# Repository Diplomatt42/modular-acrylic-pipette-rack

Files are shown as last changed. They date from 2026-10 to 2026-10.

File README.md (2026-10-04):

# Modular Acrylic Pipette Rack

Companies charge outrageous prices for equipment that scientists need to help people. This humble box project is small, but I hope it illustrates how AI can enable non-engineers like myself to quickly design products and make use of innovative companies like OSHCut and SendCutSend to reduce barriers for science.

It would be possible to create a 3D printable solution for ~$30 of filament. However, that requires a 3D printer and the hassle of managing multiple print jobs with a risk of failed prints. For not much added cost, this design eliminates that hassle and enables the use of on demand manufacturing services like OSH Cut or SendCutSend. If you have access to a laser cutter (for example through a shared University service), cost for acrylic material would be comparable to 3D printing.

This project offers two designs for the storage of serological pipettes. The solid design recreates existing storage solutions, and the column design was created to reduce material cost.

Two modular, laser-cut acrylic rack designs: **solid sides** and **corner
columns**. Stack identical compartments vertically while sharing one shelf at
each interface, instead of doubling the floor and ceiling. Designed for easy dry-fit assembly
and optimized for flat-pack shipping.

**[Download the solid CAD package](https://github.com/Diplomatt42/modular-acrylic-pipette-rack/releases/download/v1.1/solid_version_3mm_editable_CAD_package_v1.1.zip)**
| **[Download the column CAD package](https://github.com/Diplomatt42/modular-acrylic-pipette-rack/releases/download/v1.1/column_version_3mm_editable_CAD_package_v1.1.zip)**
| **[Release notes](https://github.com/Diplomatt42/modular-acrylic-pipette-rack/releases/tag/v1.1)**

Each download is a complete folder with CAD, editable source, configuration,
assembly notes and an AI handoff guide. You can use the delivered DXF/STEP files
without installing the generator.

> [!WARNING]
> Acrylic can craze or crack from alcohol-based cleaners, even in a dry-fit rack that doesn't use solvent welding.
> For regular alcohol cleaning, I strongly recommend a compatible polycarbonate
> or PETG grade instead. Verify the exact cleaner and fabrication process.
> See [solid guide](solid-version/MATERIALS_AND_CARE.md) or [column guide](column-version/MATERIALS_AND_CARE.md).

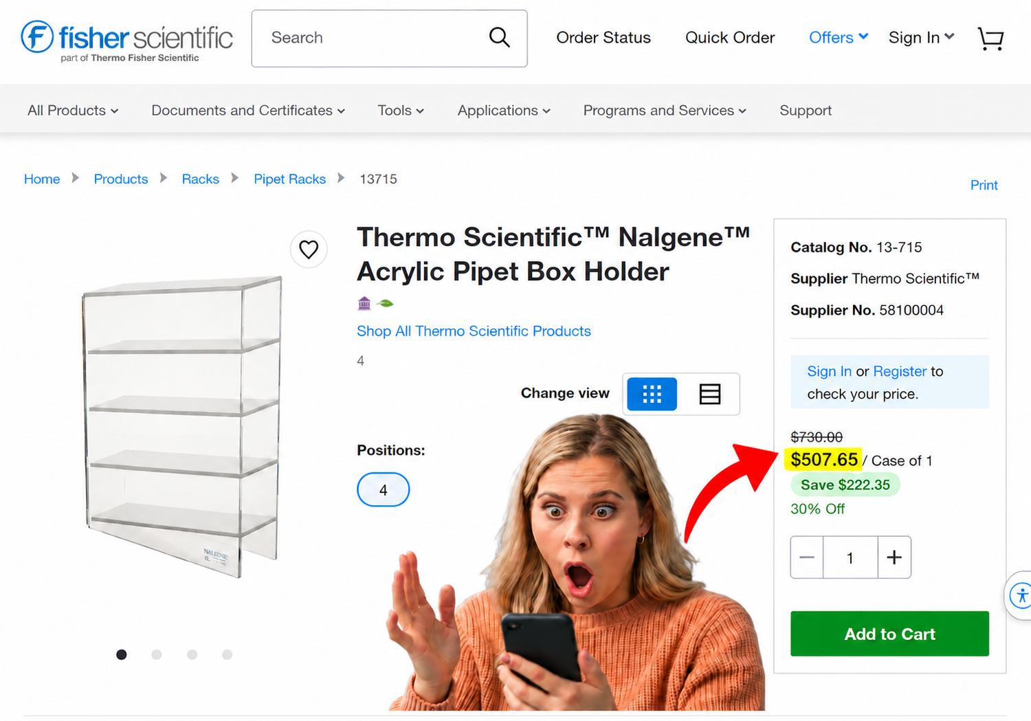
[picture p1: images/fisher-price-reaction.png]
Shocked reaction to the $507.65 Fisher Scientific product price


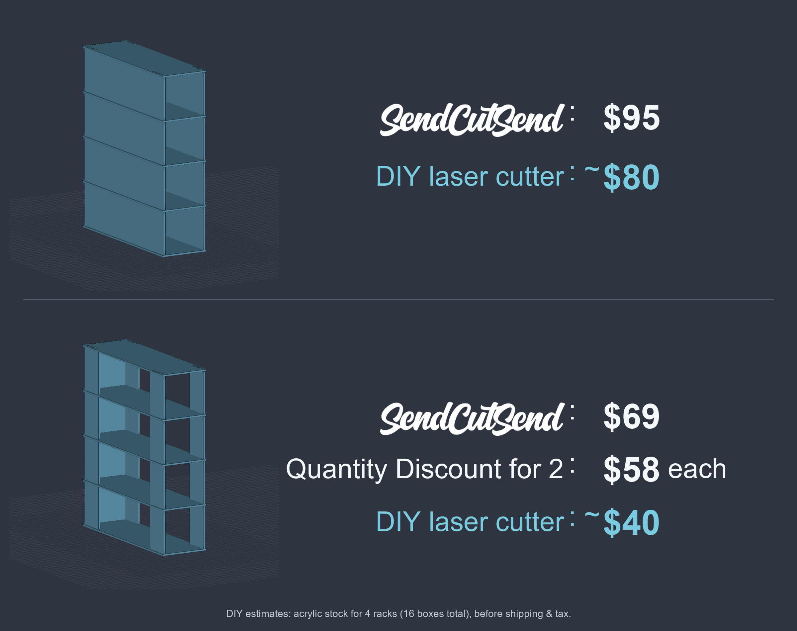
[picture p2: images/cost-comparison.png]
Solid and column rack comparison


*The SendCutSend prices are supplied quotes. DIY prices in the image are estimated
acrylic stock totals for a batch of four complete racks (16 compartments), before
shipping and tax. They are not per-rack DIY prices. Get current quotes for the same
quantity and specifications when comparing fabrication options.*

## Choose a version

| | Solid sides | Corner columns |
|---|---|---|
| Side support per compartment | Two full panels | Four identical columns |
| Column width | Not applicable | 2.000 in / 50.8 mm |
| Unique production parts | Side panel, shelf, back | Column, shelf, back |
| Four-compartment quantities | 8 sides, 5 shelves, 4 backs | 16 columns, 5 shelves, 4 backs |
| Package | [solid-version/](solid-version/) | [column-version/](column-version/) |

## Dimensions and material

- Nominal material: 3 mm clear acrylic.
- Existing model thickness: 0.118 in / 2.9972 mm; customize to measured stock.
- Body width x depth: 3.500 x 11.500 in / 88.9 x 292.1 mm.
- One complete box height: 3.500 in / 88.9 mm, including both shelves.
- Clear compartment height: 3.264 in / 82.9056 mm.
- Shelf footprint: 3.750 x 11.625 in / 95.25 x 295.275 mm.
- Four-compartment overall height: 13.646 in / 346.6084 mm.
- For N compartments: N+1 shelves, N backs, and 2N sides or 4N columns.

The default laser profile assumes a 36 x 24-inch bed. Change it to match both your
actual usable laser bed and stock dimensions. DXFs use **inches**; STEP uses **mm**.

## Assemble

1. Put the first shelf flat on a level counter.
2. Insert two sides (or four columns) and one back; temporarily support the walls.
3. Cap the compartment with a second identical shelf.
4. Add the next walls onto that shared shelf and repeat.

Upper and lower wall tabs use offset slot sets, so they do not collide at shared
shelves. Follow the assembly model for front/back and top/bottom orientation.
Full instructions: [solid assembly](solid-version/ASSEMBLY.md) /
[column assembly](column-version/ASSEMBLY.md).

## Slot locations, edges and corner radii

Hole locations and deliberately non-flush shelf edges enable the tab-and-slot
joints. The shelves extend beyond the wall faces to leave material around their
slots. Offset upper/lower slot sets let the walls above and below a shared shelf
use different openings without their tabs colliding. These offsets are intentional;
do not center the holes or trim the shelves flush without redesigning the joints.

Slots are rectangular with small **0.381 mm (0.015 in) corner radii**, preserving
the v1.0 dimensions and fit. They do not have full semicircular ends. Small radii
avoid sharp internal corners; they do not guarantee freedom from stress fractures.
Side slots are 15.24 x 3.8862 mm; back slots are 12.192 x 3.8862 mm. The default
0.889 mm thickness clearance remains a locating slip fit; cut the fit coupon to
choose a closer positive clearance for your stock and machine.

## Customize, or hand the package to an AI agent

Start with `AI_HANDOFF.md` in the chosen version. Edit `design_parameters.json`
for dimensions and joints, and `laser_profile.json` for bed size and cut spacing.
The JSON inputs use mm, including the box height, actual stock thickness and fit
clearances. The generator recomputes the mating parts and shared-shelf stack.

Example request:

> Change the single-box overall height to 101.6 mm, keep the shared shelf system,
> and regenerate the one-box and four-compartment STEP models and production
> DXFs. Validate the CAD and report the new clear opening height.

The source uses Python, CadQuery and ezdxf. Setup and regeneration instructions
are in each package's README. Use a new output folder to preserve earlier revisions.

| Reference | Solid | Column |
|---|---|---|
| Editable inputs and instructions | [README](solid-version/README.md) | [README](column-version/README.md) |
| AI handoff | [AI_HANDOFF.md](solid-version/AI_HANDOFF.md) | [AI_HANDOFF.md](column-version/AI_HANDOFF.md) |
| Laser customization | [CUSTOMIZATION.md](solid-version/CUSTOMIZATION.md) | [CUSTOMIZATION.md](column-version/CUSTOMIZATION.md) |
| Three production DXFs | [cutting/](solid-version/generated/cutting/) | [cutting/](column-version/generated/cutting/) |
| Individual and assembled STEP | [models/](solid-version/generated/models/) | [models/](column-version/generated/models/) |

## Prototype status and validation

**CAD-validated prototype; physical testing is still needed.** No load rating or
unlimited safe stack height is claimed. The joints are gravity-assembled locating
slip fits; they do not positively retain the stack when lifted by its top.

The rack was designed to be modular, dry-fit together for easy assembly, and
optimized for flat-pack shipping. All production parts are flat sheet pieces that
can ship disassembled. Walls need temporary support until the next shelf is fitted.

If additional stability is needed, acrylic can be permanently solvent welded with
a compatible acrylic cement. Where permitted under approved lab controls,
methylene chloride and a needle applicator can be used at close-contact seams;
other acrylic cement formulations are available. Bonding prevents disassembly at
those joints. See the [solid](solid-version/MATERIALS_AND_CARE.md) or
[column](column-version/MATERIALS_AND_CARE.md) material guide for joint-gap guidance,
chemical precautions, and the [author's example cement link](https://a.co/d/034aoZOj).

Checks passed for closed DXF contours, solid geometry, assembly collisions, STEP
reimport, dimensions, part quantities and bed-layout spacing. The rewritten source
also reproduces the previously shared parts. The v1.1 documentation release
retains the v1.0 CAD geometry and confirms the small rounded slot corners in both
versions. Tested customizations include height
changes and changes to stock thickness, clearance, bed size and compartment count.

Cut a fit coupon with your stock and settings, then prototype one compartment.
DXFs describe finished geometry; apply kerf compensation once in your laser CAM.
Changing the modeled thickness alone does not calibrate your laser.

See each version's `BASELINE_CHECK.json` and `generated/validation_report.json`
for the actual checks. Local nested drawings are separate from the individual
supplier DXFs and do not guarantee the fewest possible sheets.

## License and credit

Original project material is licensed under **[CC BY 4.0](https://creativecommons.org/licenses/by/4.0/)**.
You can use, modify and redistribute it, including commercially, with attribution,
a license link and an indication of changes. Copyright is retained to the extent
it applies. See [LICENSE](LICENSE) and [ATTRIBUTION.md](ATTRIBUTION.md).

Third-party libraries and the SendCutSend logo/trademarks retain their own rights.
This project is not affiliated with or endorsed by SendCutSend.

## Feedback and contributions

Open an issue with your variant, stock thickness, machine/setup, changed parameters
and the problem encountered. If you submit improved geometry or instructions,
include matching source/input changes and regenerated validation results.

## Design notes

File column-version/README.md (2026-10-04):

# Editable 3 mm acrylic modular box: column version

This package includes finished CAD files and the editable inputs needed to change
the design. It uses four identical 2-inch columns, one at each corner, one back panel per compartment,
and one shelf at each horizontal interface. Adjacent compartments share a shelf.

The current CAD is a gravity-assembled locating **slip fit**, not a press-fit or
positively locked assembly. Physical fit and load capacity have not been tested.

> [!WARNING]
> Acrylic can craze or crack from alcohol-based cleaners, even in a dry-fit rack that doesn't use solvent welding.
> For regular alcohol cleaning, I strongly recommend a compatible polycarbonate
> or PETG grade instead. Verify the exact cleaner and fabrication process.
> See [materials and cleaning guidance](MATERIALS_AND_CARE.md).

## Start here

- `generated/cutting/`: three unique, individual production DXFs.
- `generated/models/`: individual part STEP models, one complete compartment,
  and a four-compartment stack.
- `design_parameters.json`: dimensions and joint clearances, all in mm.
- `laser_profile.json`: laser bed, edge margin, spacing, and feature limits.
- `source/generate.py`: portable parametric source; no local machine paths.
- `generated/laser_layouts/`: nested DXFs for your own laser, plus placement data
  in the validation report. These contain multiple parts; do not upload them as
  individual SendCutSend parts.
- `generated/calibration/`: fit ladder and probe, with a separate slot map.
- `ASSEMBLY.md`, `CUSTOMIZATION.md`, `AI_HANDOFF.md`: assembly and editing guidance.
- `MATERIALS_AND_CARE.md`: alcohol warning, material choices and optional bonding.
- `generated/cut_list.csv`: quantities for the configured compartment count.
- `generated/validation_report.json`: actual checks and remaining limitations.
- `MANIFEST.sha256`: checksums of included files.

Designed for modular, easy dry-fit assembly and flat-pack shipping.
See ASSEMBLY.md for intentional joint offsets and non-flush shelf edges,
and MATERIALS_AND_CARE.md for cleaning, alternate materials and optional cement.

**v1.1 updates the documentation; delivered CAD geometry is unchanged from v1.0.**
The rectangular slots retain 0.381 mm corner radii and existing clearances.

## Default dimensions

| Dimension | Value |
|---|---|
| Body width x depth | 3.500 x 11.500 in (88.9 x 292.1 mm) |
| Single-box overall height, including both shelves | 3.500 in (88.9 mm) |
| Clear compartment height | 3.264 in (82.9056 mm) |
| Clear compartment width | 3.264 in (82.9056 mm) |
| Shelf footprint | 3.750 x 11.625 in (95.25 x 295.275 mm) |
| Four-compartment overall height | 13.646 in (346.6084 mm) |
| Column width / side joint zone width | 2.000 in (50.8 mm) |
| Nominal stock | 3 mm acrylic |
| Thickness used by existing CAD | 0.118 in (2.9972 mm) |
| Slot thickness width | 0.153 in (3.8862 mm) |

The 0.0028 mm difference between nominal 3 mm and the existing model is retained
to reproduce the already shared CAD. Set `stock_model_thickness` to your measured
sheet thickness when customizing; dependent dimensions are recalculated.

## Regenerate

Use Python 3.11 or 3.12 in a fresh virtual environment. The pinned dependencies
match the generator's tested environment. CAD dependencies are downloaded by pip;
they are not bundled in this ZIP.

Windows:

```powershell
python -m venv .venv
.venv\Scripts\python -m pip install -r requirements.txt
.venv\Scripts\python source/generate.py --output generated_custom
```

macOS / Linux:

```sh
python3 -m venv .venv
.venv/bin/python -m pip install -r requirements.txt
.venv/bin/python source/generate.py --output generated_custom
```

Edit the two JSON inputs first. The output directory must be new or empty; this
preserves previous revisions and prevents obsolete nested sheets from lingering.
Alternative inputs can be supplied with `--config` and `--laser-profile`.

## File units and compensation

Production and calibration DXFs are R2010, 1:1 **inch** units, using only LINE and
ARC cutting entities on layer 0. STEP models use **mm**. If an importer ignores DXF
units, select inches: the shelf is 3.750 x 11.625 inches, not millimetres.

These DXFs describe the desired finished geometry, not kerf-offset toolpaths.
`measured_kerf_mm` records your measurement; it does not offset the files. Let your
laser CAM compensate once, with the correct inside/outside direction. Cutting
on the line without compensation changes outside dimensions and slot widths.

## Quantity rule

For N compartments: N+1 shelves, N backs, and 4N columns. Four compartments
therefore use five shelves. Increasing the count does not duplicate an interface.

## Validation and limits

The generator audits DXF contours, imports the actual DXFs into CAD, validates
solid geometry, checks nominal body collisions, reimports assembly STEP files,
checks envelopes and bottom position, and verifies nesting bounds and spacing.
Feature-limit checks use editable targets in `laser_profile.json`; they are not
a blanket approval for any supplier, machine, thickness, or load.

Default nesting is conservative bounding-box packing. It does not prove the
fewest possible sheets. Fit-ladder parts are extra and are not included in the
production cut list or nested layouts. Save scraps for them.

Large stacks, heavier contents, altered height, narrower columns, and tighter
fits need physical evaluation. The floor is flat on the counter only if its tabs
remain shorter than the actual material thickness. Inspect regenerated previews
or STEP models and cut a coupon before a production batch.

The original `modular_acrylic_box_rev4_1p6mm_CAD_package (1).zip` is historical:
it used separate top/floor pieces, 1.6 mm stock, and solvent-weld assembly. This
package replaces that geometry with the current shared-shelf 3 mm design; do not
mix the old parts or assembly instructions into this revision.

`reference_previews/` contains images of the delivered default revision. The generator does not regenerate these images; inspect customized STEP models separately.

## License

Original package material is licensed CC BY 4.0. Commercial reuse is permitted with attribution, a license link and change notices. See LICENSE and ATTRIBUTION.md. Third-party dependencies retain their own licenses.

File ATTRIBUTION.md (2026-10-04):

# Attribution and license scope

Original project: Modular Acrylic Pipette Rack
Project attribution: Diplomatt42
Source: https://github.com/Diplomatt42/modular-acrylic-pipette-rack
Copyright notice: Copyright (c) 2026 Diplomatt42, to the extent copyright applies.

The original CAD files, design parameters, generator source, documentation, and
original renderings in this repository are licensed under Creative Commons
Attribution 4.0 International (CC BY 4.0). See LICENSE for the full terms.

When sharing original or modified material, retain the attribution and license
notice, link to the project and license, and indicate modifications. Commercial
reuse is permitted. Do not imply endorsement by the project author.

Suggested credit:
"Based on Modular Acrylic Pipette Rack by Diplomatt42, licensed CC BY 4.0.
Source: https://github.com/Diplomatt42/modular-acrylic-pipette-rack. Changes: [describe your changes]."

Third-party libraries remain under their own licenses and are not bundled in
the packages. The SendCutSend logo and trademarks in the price comparison image
belong to their respective owner and are excluded from this project's license.
Their inclusion does not imply affiliation, sponsorship, or endorsement.

Fisher Scientific screenshot content, product photo, and branding retain their owners' rights and are excluded from this project's CC BY license.

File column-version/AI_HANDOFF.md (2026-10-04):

# AI handoff: column version

This document is optional task guidance for someone deliberately asking an AI
agent to modify this package. The recipient's explicit request takes precedence.

## Design intent to preserve

- Three unique production parts: column, shelf, back panel.
- One shared shelf between adjacent compartments, N+1 shelves for N compartments.
- Open front, 3 mm nominal acrylic, flat bottom shelf on a counter.
- Repeat identical walls and shelves vertically; no separate top part.
- Four identical 50.8 mm corner columns per compartment.
- Upper/lower tab centers remain offset at shared shelves to avoid collisions.
- Non-flush shelf edges leave material around the intentionally placed slots.
- Rectangular slots have small 0.381 mm corner radii; retain their envelope
  and clearance unless the recipient explicitly requests a joint redesign.
- Modular dry-fit assembly and disassembled flat-pack shipping are design goals.
- Finished-part DXFs, not pre-offset toolpaths. STEP assemblies preserve separate
  bodies. Current joints are locating slip fits, not positively retained joints.

## Work procedure

1. Read README.md, CUSTOMIZATION.md, ASSEMBLY.md, MATERIALS_AND_CARE.md, and
   both JSON inputs. Keep the alcohol-cleaning warning in modified packages.
2. Make the requested change in JSON first. Update source only if new geometry
   cannot be expressed by the existing parameters. Use relative paths; never
   depend on the original author's desktop paths or an original ChatGPT session.
3. Install requirements into a virtual environment and run source/generate.py
   with a new output directory. Preserve the delivered reference revision.
4. Inspect generated/validation_report.json, or the report in your custom output.
   Report nominal collisions, topology errors, undersized bridges, units problems,
   and nesting failures. Do not suppress failed checks to ship an invalid design.
5. Review single-box and stack STEP assemblies visually. Compare the requested
   dimension to actual bounds and keep part quantities consistent with N.
6. Recheck the user's stock thickness, machine limits, kerf-compensation workflow,
   and fit coupon. Unknown measurements are unknown; do not invent measured data.
7. If changing material for frequent alcohol cleaning, verify the exact grade,
   cleaner and process. Polycarbonate/PETG are recommended candidates; the
   delivered acrylic CAD does not certify an alternate-material build.
8. Deliver the three unique production DXFs, part/assembly STEP models, revised
   input JSON, source, cut list, validation report, and a concise change note.
   Keep local nested layouts separate from individual supplier DXFs.

## Example prompts a recipient can use

> Change the single-box overall height to 101.6 mm, keeping the width, depth,
> material and shared-shelf interface. Regenerate both the one-compartment and
> four-compartment assemblies, validate them, and show the resulting clear height.

> Adapt this package to my CO2 laser with a 600 x 400 mm usable bed. My acrylic
> measures 3.05 mm thick and my measured kerf is 0.15 mm. Start with a 0.20 mm
> positive slot clearance. Keep finished-part DXFs, make a fit coupon, record the
> compensation workflow, and produce bed layouts for two four-compartment racks.

> I want 100 mm of CLEAR compartment height. Compute the outside single-box height
> from the actual thickness, update the walls and stacked model, and keep the
> number of shelves at N+1.

No physical fit or load certification is implied by successful CAD validation.

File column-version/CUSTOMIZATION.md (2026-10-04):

# Customization and laser setup

## Change height

Edit `geometry_mm.single_box_overall_height` in `design_parameters.json`.
This is outside height of one complete box, including its two shelves.
For a 4-inch overall box, use 101.6 mm. For a desired clear opening H, use
H + 2 * stock_model_thickness. The generator updates wall height and stack pitch.

For N compartments:

- clear height = single_box_overall_height - 2 * stock_model_thickness
- repeat pitch = clear height + stock_model_thickness
- stack height = N * clear height + (N+1) * stock_model_thickness

The shared shelf DXF does not change for height-only edits.

## Adapt to a different laser or sheet

1. Read [MATERIALS_AND_CARE.md](MATERIALS_AND_CARE.md), especially before
   choosing material for regular alcohol cleaning. Confirm your machine supports
   the actual sheet material and thickness, and follow your lab's process.
   Polycarbonate/PETG substitutions need new fit and structural checks;
   do not assume acrylic laser settings or cement remain appropriate.
2. Measure actual sheet thickness at several points. Set
   `geometry_mm.stock_model_thickness` accordingly. Nominal thickness is not a
   guarantee of actual thickness or uniformity.
3. Update `laser_profile.json`: actual usable bed dimensions, edge margins,
   inter-part spacing, minimum feature limits, and `racks_to_nest`.
   Enter a bed that is no larger than the available stock. Uniform edge margins
   model edge keepouts; irregular clamps need manual layout review.
4. Measure kerf using your actual settings and record `measured_kerf_mm`.
   This field is metadata; it does not perform compensation. Apply compensation
   once in your laser software. Power, speed, focus and passes depend on the
   machine and material, and are intentionally not guessed by the generator.
5. Cut `generated/calibration/fit_ladder.dxf` and `fit_probe.dxf` from the same
   stock. Read `slot_map.csv`: slots are numbered bottom-to-top in the DXF.
   Insert the probe edge-first so stock thickness crosses the narrow dimension.
   The probe width is the side tab width; slot length is the corresponding side
   slot length. This checks fit width, not structural retention or a complete joint.
6. Select a positive slip clearance and set `joints_mm.slot_thickness_clearance`.
   Slot width = modeled sheet thickness + this clearance. Both variants use the
   same shelf outline and slot scheme with identical input settings.
7. Review the STEP models and validation report, then prototype one compartment.

Default clearance is 0.889 mm, carried over from the supplier-oriented design.
Your calibrated laser may allow a closer slip fit. Avoid claiming a friction-fit
load rating from a clearance setting; this source requires positive clearance.
The fit ladder includes 0.05, 0.10, 0.15, 0.20, 0.30, 0.50 and 0.889 mm samples.

## Change other geometry

- `body_width`: recalculates internal width and the back tab center fractions.
- `body_depth`: moves the rear columns and all rear joint slots together.
- `column_width`: controls each column and the common shelf's side joint zones,
  including in the solid version. Default is 50.8 mm. Changing it therefore also
  changes shelf slots; regenerate all interacting parts together.
- `shelf_overhang`: affects side and rear margins around the shelf slots.
- `tab_projection`: must remain below the actual stock thickness and long enough
  to seat reliably. Changing it affects the mating joint and bottom clearance.
- `corner_radius`: default 0.381 mm small fillets on cutting corners, including
  rectangular slot corners. Preserve the existing slot envelope and fit; this
  revision does not use full semicircular ends. Radius must fit every short feature.
- `side_tab_width`, `back_tab_width`, slot length clearances: change matching tab
  and slot features together. Slot length clearance is TOTAL, not per side.
- `back_tab_fractions`: advanced joint placement, relative to internal width.
  Each lower/upper edge requires two tabs; keep their slots separate.

The current solid and column packages are compatible only when their shared
geometry and joint settings match. Height-only changes keep the shelves compatible.

## What the checks do and do not prove

Checks reject open/ambiguous contours, invalid CAD solids, nominal intersections,
incorrect assembly dimensions, insufficient specified bridges, and invalid bed
layouts. They do not simulate cutting, elastic deflection, fracture, process
tolerances, friction, or tipping. Nesting can be improved manually or by a better
nesting tool; keep cut paths separate and respect gap/margin settings.

The generated `laser_layouts` folder contains multiple-part drawings for local
cutting. For SendCutSend, submit each unique DXF from `cutting` separately with the
cut-list quantities. Check current supplier guidelines before ordering; the
included legacy feature thresholds are configurable targets, not current approval.

Useful references:
- https://sendcutsend.com/guidelines/getting-started/
- https://sendcutsend.com/materials/acrylic/
- https://cadquery.readthedocs.io/
- https://ezdxf.readthedocs.io/

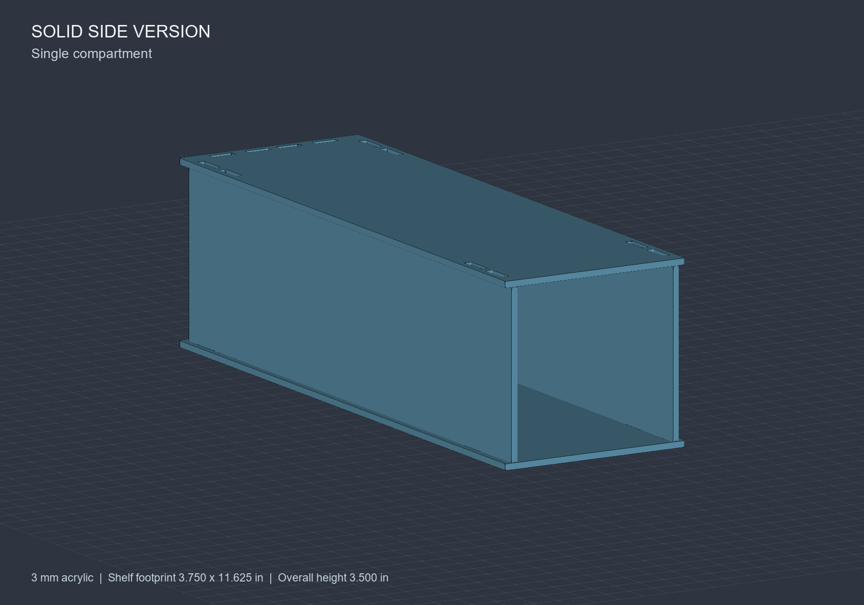
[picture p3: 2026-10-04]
solid-version/reference_previews/one_box.png

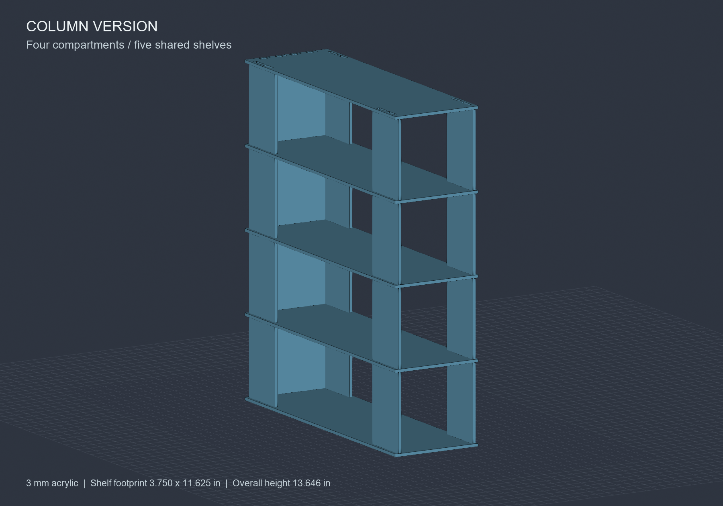
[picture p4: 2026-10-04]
column-version/reference_previews/four_compartment_stack.png

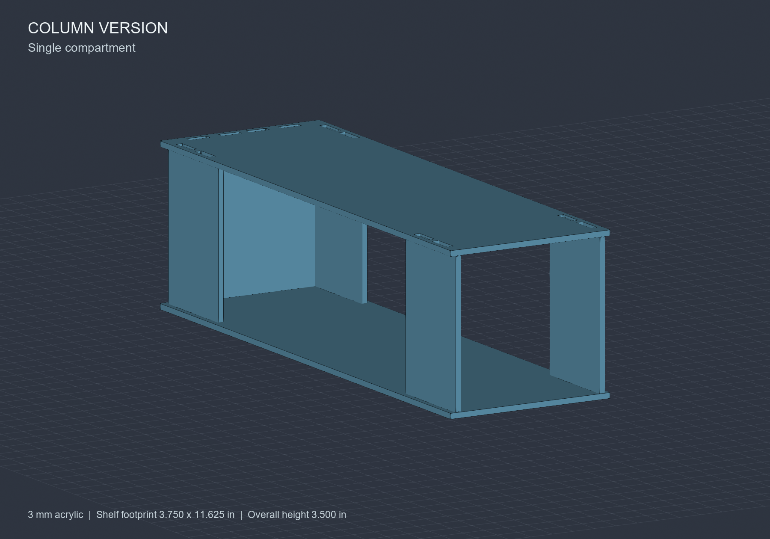
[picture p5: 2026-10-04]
column-version/reference_previews/one_box.png

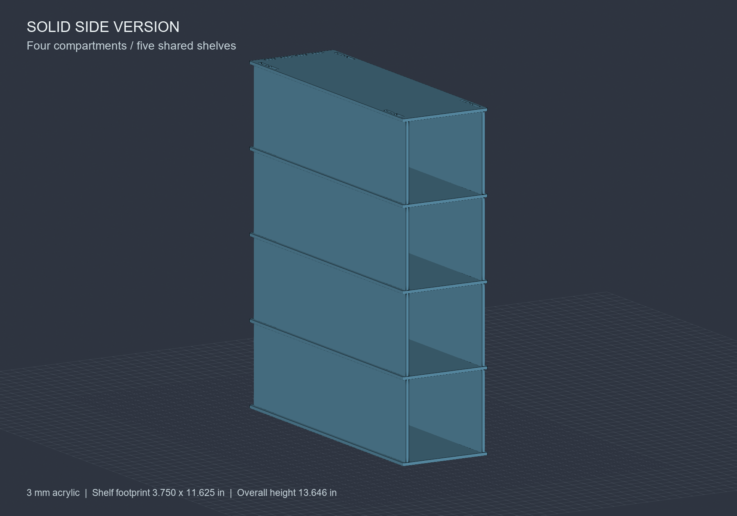
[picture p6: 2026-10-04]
solid-version/reference_previews/four_compartment_stack.png

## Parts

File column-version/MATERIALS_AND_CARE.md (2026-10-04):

# Materials, cleaning and optional bonding

## Important: alcohol-based cleaning

**Acrylic can craze or crack when exposed to alcohol-based cleaners, including
repeated alcohol cleaning of a dry-fit rack. This vulnerability exists even
without solvent-welded joints. For environments that regularly clean with alcohol
solutions, I strongly recommend choosing a suitable polycarbonate or PETG sheet
instead of acrylic.**

Confirm compatibility with the sheet manufacturer for your exact grade, cleaner,
concentration, contact time and use conditions. Alternatives are not universally
resistant to every disinfectant: [Plaskolite's compatibility guide](https://plaskolite.com/docs/default-source/tec/tec275_psk_disinfect.pdf)
lists alcohol-compatible TUFFAK polycarbonate and VIVAK PETG, and explains the
effects of stress and repeated exposure.

For ordinary acrylic cleaning, use mild soap, water and a soft cloth. Use only a
manufacturer-approved cleaner or disinfectant for the exact sheet. Some acrylic
grades permit specific diluted alcohol formulations; that is not approval for
routine lab-strength alcohol cleaning. See [ACRYLITE care guidance](https://www.acrylite.co/resources/fabrication-manuals/clean-disinfect-and-maintain-acrylite-acrylic-sheet).

## Changing the sheet material

The delivered CAD and validation are for nominal 3 mm acrylic. Polycarbonate and
PETG are material alternatives to evaluate, not separately validated builds here.
Measure thickness, recalibrate the joint fit, and reassess shelf deflection and
stack stability. Confirm that your fabrication process supports the exact sheet
and thickness; do not reuse acrylic laser settings automatically. Polycarbonate
can give poor CO2-laser cut results, including discoloration; consult your machine
provider or use a suitable machining process. See [Epilog's polycarbonate guidance](https://www.epiloglaser.com/how-it-works/faq/can-you-cut-engrave-polycarbonate-with-laser-machine/).

## Optional solvent welding for added stability

The rack is designed for modular, easy dry-fit assembly and flat-pack shipping.
If additional stability is needed after fitting and squaring an acrylic prototype,
compatible acrylic cement can permanently bond the panel-to-shelf seams.
Thin capillary cement may be applied with a needle applicator where edges are in
close contact. The default loose tab-slot gaps are not close-contact seams; use
a cement intended for the actual gap and follow its instructions.

Methylene chloride (dichloromethane) is an acrylic-bonding solvent, but it is
hazardous and regulated. Use it only where permitted under your lab's approved
controls and the product SDS. [EPA's guidance](https://www.epa.gov/assessing-and-managing-chemicals-under-tsca/risk-management-methylene-chloride)
describes US restrictions. Acrylic cements with other formulations are available;
see [ACRIFIX solvent cements](https://www.acrylite.co/products/brands/acrifix/solvent-cements).

[Example acrylic-cement product link supplied by the project author](https://a.co/d/034aoZOj).
Check the actual product's formulation and suitability; the link is not a tested
joint specification. Bonding prevents disassembly at the bonded joints and does
not establish a load rating or make acrylic alcohol-resistant.

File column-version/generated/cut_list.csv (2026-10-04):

part | quantity_per_rack | quantity_to_nest | width_mm | height_mm | stock_thickness_mm
shelf | 5 | 5 | 95.25 | 295.27500000000003 | 2.9972
column | 16 | 16 | 50.8 | 86.9188 | 2.9972
back_panel | 4 | 4 | 82.9056 | 86.9188 | 2.9972

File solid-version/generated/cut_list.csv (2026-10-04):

part | quantity_per_rack | quantity_to_nest | width_mm | height_mm | stock_thickness_mm
shelf | 5 | 5 | 95.25 | 295.27500000000003 | 2.9972
side_panel | 8 | 8 | 292.1 | 86.9188 | 2.9972
back_panel | 4 | 4 | 82.9056 | 86.9188 | 2.9972

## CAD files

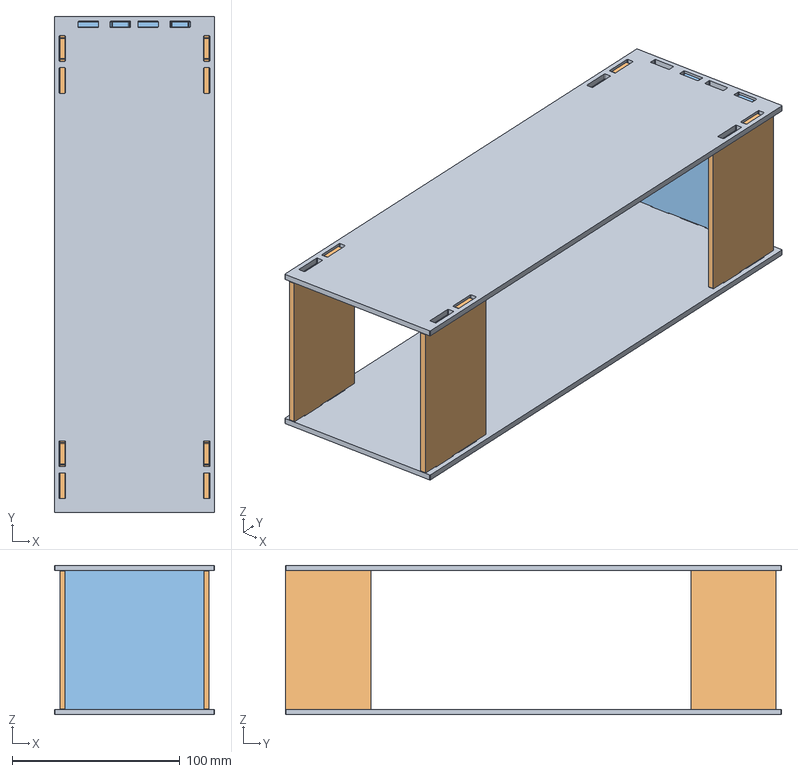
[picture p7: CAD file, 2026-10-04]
column-version/generated/models/one_complete_box.step
95.2 x 295.3 x 88.9 mm
Shelf_0
Shelf_1
Left_Front_0
Left_Rear_0
Right_Front_0
Right_Rear_0
Back_0

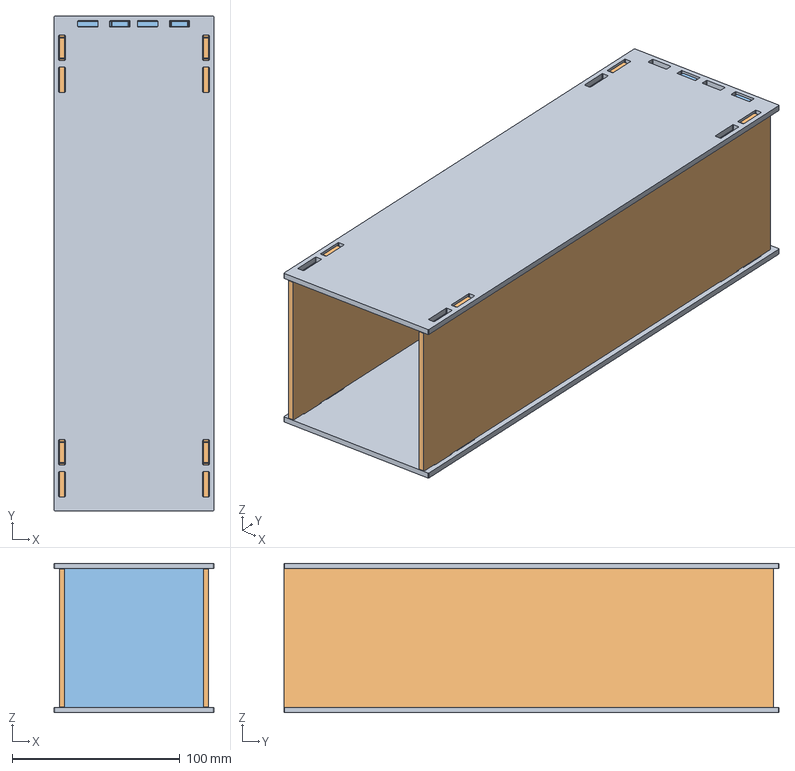
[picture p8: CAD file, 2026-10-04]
solid-version/generated/models/one_complete_box.step
95.2 x 295.3 x 88.9 mm
Shelf_0
Shelf_1
Left_Full_0
Right_Full_0
Back_0

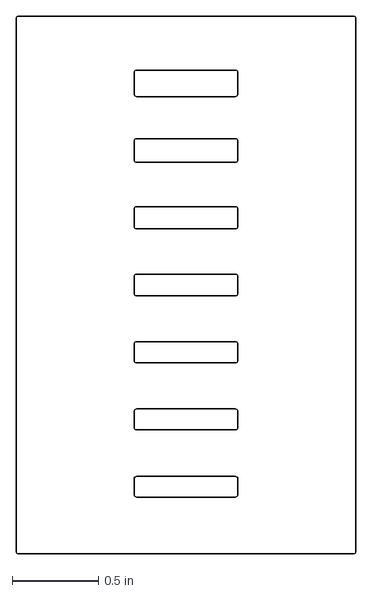
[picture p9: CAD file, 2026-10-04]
column-version/generated/calibration/fit_ladder.dxf
1.97 x 3.11 in

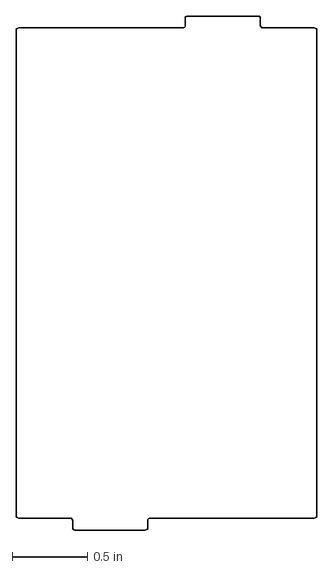
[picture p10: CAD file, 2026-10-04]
column-version/generated/cutting/column.dxf
2.00 x 3.42 in

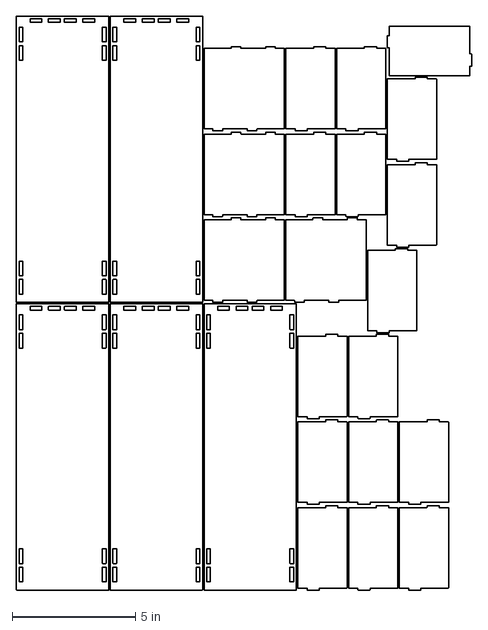
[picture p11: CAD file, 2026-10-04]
column-version/generated/laser_layouts/sheet_01.dxf
18.5 x 23.3 in

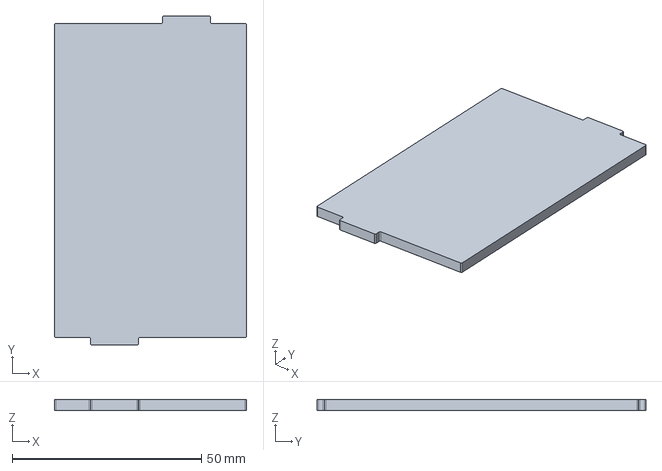
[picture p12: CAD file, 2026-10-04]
column-version/generated/models/part_column.step
50.8 x 86.9 x 3.00 mm

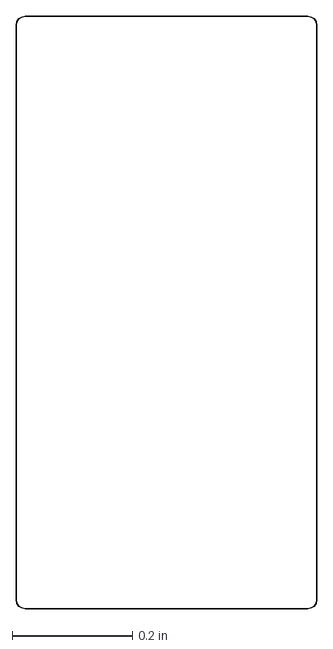
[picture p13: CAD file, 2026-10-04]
solid-version/generated/calibration/fit_probe.dxf
0.5 x 0.984 in

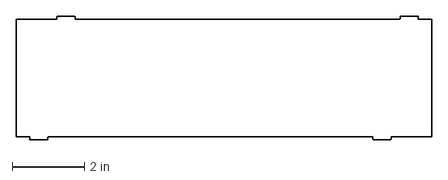
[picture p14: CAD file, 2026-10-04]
solid-version/generated/cutting/side_panel.dxf
11.5 x 3.42 in

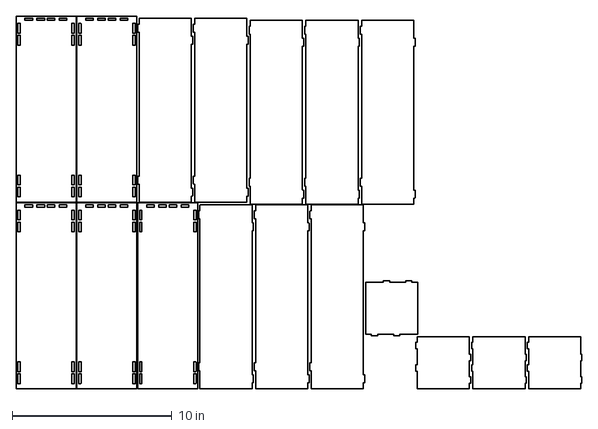
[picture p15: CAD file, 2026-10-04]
solid-version/generated/laser_layouts/sheet_01.dxf
35.4 x 23.3 in

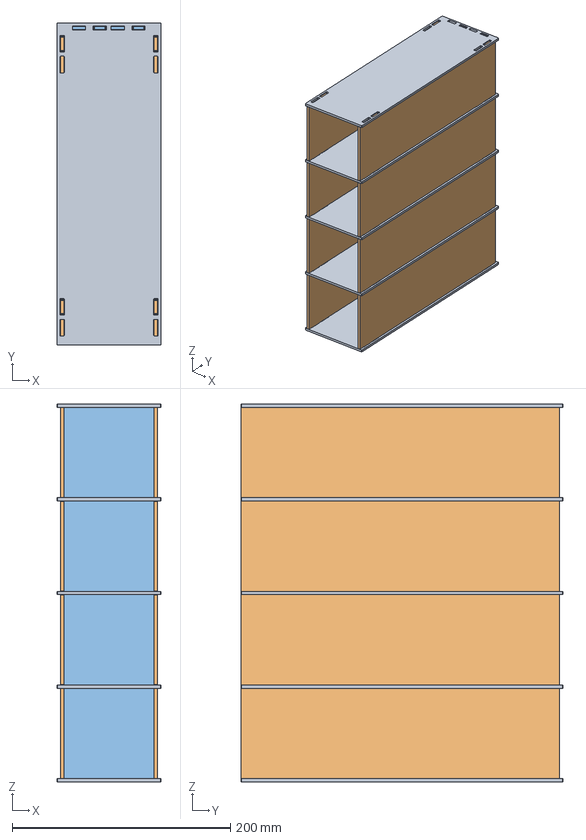
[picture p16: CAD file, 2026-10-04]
solid-version/generated/models/4_compartment_stack.step
95.2 x 295.3 x 346.6 mm
Shelf_0
Shelf_1
Shelf_2
Shelf_3
Shelf_4
Left_Full_0
Right_Full_0
Back_0
Left_Full_1
Right_Full_1
Back_1
Left_Full_2
Right_Full_2
Back_2
Left_Full_3
Right_Full_3
Back_3

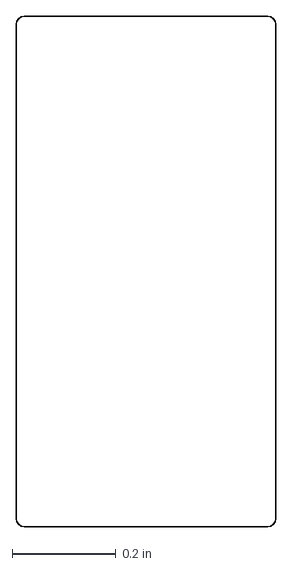
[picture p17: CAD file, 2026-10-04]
column-version/generated/calibration/fit_probe.dxf
0.5 x 0.984 in

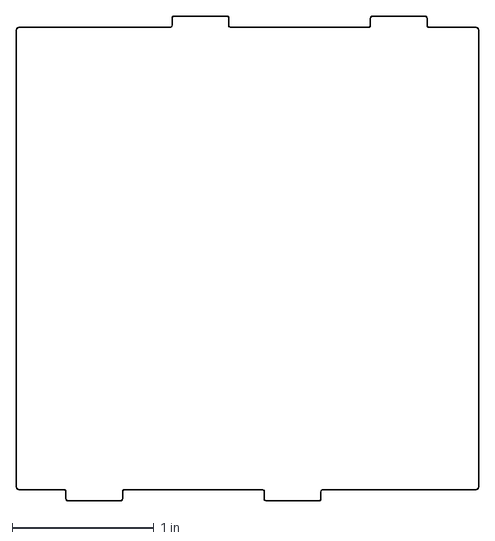
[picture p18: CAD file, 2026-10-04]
column-version/generated/cutting/back_panel.dxf
3.26 x 3.42 in

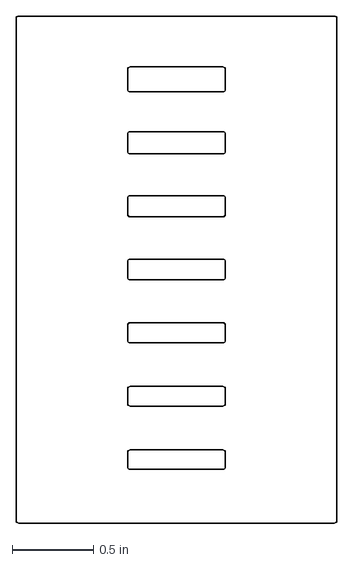
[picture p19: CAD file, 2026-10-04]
solid-version/generated/calibration/fit_ladder.dxf
1.97 x 3.11 in

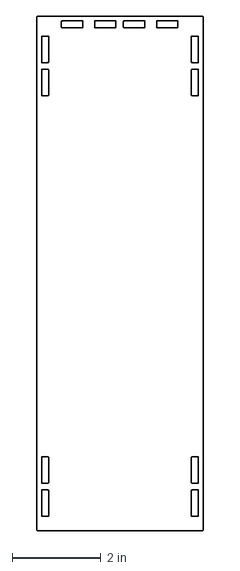
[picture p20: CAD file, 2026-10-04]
solid-version/generated/cutting/shelf.dxf
3.75 x 11.6 in

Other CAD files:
column-version/generated/cutting/shelf.dxf
column-version/generated/models/part_back_panel.step
solid-version/generated/cutting/back_panel.dxf
solid-version/generated/models/part_back_panel.step
column-version/generated/models/4_compartment_stack.step
column-version/generated/models/part_shelf.step
solid-version/generated/models/part_shelf.step
solid-version/generated/models/part_side_panel.step

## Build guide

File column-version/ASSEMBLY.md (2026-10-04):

# Assembly reference: column version

Coordinate system: X is shelf width; Y runs from the open front toward the back;
Z points upward. The bottom shelf underside is Z=0. The front is open and has
no retaining lip or incline.

1. Place one shelf flat on a level counter. Its twelve slots are the same on every
   shelf; front/back orientation matters. Use the STEP model to identify the rear
   crosswise slots, which are close to the back edge.
2. Add four identical 2-inch columns, one at each corner and a back panel. Lower wall tabs enter the A slot set.
   Hold or temporarily brace the walls until the upper shelf caps them.
3. Place a second identical shelf on those walls. Upper wall tabs enter the B slot
   set; the A slots on this shared shelf are available for the next compartment.
4. Add the next set of walls onto the shared shelf and repeat. Four compartments
   finish with five shelves.
5. Check that the assembly is square, the base sits flat, and all tabs are seated.

The two side tabs at each joint zone have asymmetric positions: lower tabs are
at 31.25% of the 2-inch zone; upper tabs are at 68.75%. Back-panel upper and lower
tabs are offset as well. Do not reverse a wall vertically or use one slot set
for both opposing walls. The lower and upper tab outlines identify orientation.

Corner wall edges abut without vertical corner connectors. Shelves locate the
walls; no adhesive, fastener, or retainer is included. Current clearances are
deliberately loose and do not hold a rack together when lifted by its top. Move
it with support underneath or disassemble it. Acrylic press fits can crack and
are not obtained simply by setting clearance to zero.

Default tab projection is 2.0066 mm and model thickness is 2.9972 mm, leaving
0.9906 mm nominal clearance underneath the lower tabs inside the bottom shelf.
If your sheet is thinner than the projection, tabs will contact the counter.

There is no certified load rating or unlimited safe stack height. Changing the
height or compartment count requires reassessing sway, racking, and tipping.

## Slot locations, edges and corner radii

Hole locations and deliberately non-flush shelf edges enable the tab-and-slot
joints. The shelves extend beyond the wall faces to leave material around their
slots. Offset upper/lower slot sets let the walls above and below a shared shelf
use different openings without their tabs colliding. These offsets are intentional;
do not center the holes or trim the shelves flush without redesigning the joints.

Slots are rectangular with small **0.381 mm (0.015 in) corner radii**, preserving
the v1.0 dimensions and fit. They do not have full semicircular ends. Small radii
avoid sharp internal corners; they do not guarantee freedom from stress fractures.
Side slots are 15.24 x 3.8862 mm; back slots are 12.192 x 3.8862 mm. The default
0.889 mm thickness clearance remains a locating slip fit; cut the fit coupon to
choose a closer positive clearance for your stock and machine.

## Flat-pack assembly and optional stability

Identical flat sheet parts support easy modular dry-fit assembly and compact
flat-pack shipping. Pack them disassembled and protect the exposed tab tips.
Compatible acrylic cement can permanently bond an assembled rack if extra
stability is needed. See [MATERIALS_AND_CARE.md](MATERIALS_AND_CARE.md) for cement
selection, needle application at close-contact seams, and methylene chloride
restrictions. Bonded joints cannot be taken apart for flat-pack transport.

**Cleaning warning:** alcohol-based cleaners can damage acrylic even without
solvent welding. For frequent alcohol cleaning, use a compatible polycarbonate
or PETG grade and revalidate fabrication and fit; see the material guide above.

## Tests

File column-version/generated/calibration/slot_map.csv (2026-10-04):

slot_from_bottom | nominal_clearance_mm | finished_slot_width_mm
1 | 0.05 | 3.0471999999999997
2 | 0.1 | 3.0972
3 | 0.15 | 3.1471999999999998
4 | 0.2 | 3.1972
5 | 0.3 | 3.2971999999999997
6 | 0.5 | 3.4972
7 | 0.889 | 3.8861999999999997

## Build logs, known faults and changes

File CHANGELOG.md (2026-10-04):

# Changelog

## v1.1

- Retains the v1.0 CAD dimensions, locating clearances and rectangular slots with
  small 0.381 mm corner radii. No full-semicircle slot revision was published.
- Both designs regenerated and checked against delivered DXFs; validated STEP
  assemblies, dimensions, quantities and bed layouts. No physical testing claimed.
- Adds a prominent alcohol-cleaning warning, including for dry-fit acrylic, and
  recommends suitable polycarbonate/PETG grades for regular alcohol cleaning.
- Adds self-contained material/care guidance to both downloadable packages.
- Documents modular easy dry-fit assembly, flat-pack shipping, deliberate slot
  offsets and non-flush shelf edges, and optional permanent acrylic cement bonding.
- Preserves the v1.0 release as a historical download.

## v1.0

- Initial public release of the 3 mm shared-shelf modular acrylic rack.
- Solid-side and 2-inch corner-column variants; three unique cut parts each.
- Individual DXFs and STEP models; one-box and four-compartment assemblies.
- Editable parameters, laser profiles, source generator, fit coupons and layouts.
- Assembly instructions, AI handoff guidance, and checked geometry reports.
- CC BY 4.0 licensing with attribution and modification notices.
- Prototype release: physical fit, load capacity and stack stability untested.

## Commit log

2026-10-04 Publish editable 3 mm shared-shelf acrylic rack designs
    [4_compartment_stack.step, back_panel.dxf, column.dxf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]
2026-10-04 Preserve CAD and checksum bytes across platforms
    [back_panel.dxf, column.dxf, cut_list.csv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]
2026-10-04 Document cleaning compatibility, modular assembly and retained rounded slots
